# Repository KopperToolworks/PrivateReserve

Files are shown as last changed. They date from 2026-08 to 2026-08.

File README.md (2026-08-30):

# Private Reserve

Private Reserve is a door controller for openings that a stock garage opener is a poor fit for: a concealed or architectural door, a 140 V DC motor without the manufacturer's logic board, and a close that must seat against the frame rather than hit a hard stop.

It follows a Door-pace S-curve on remaining throw (peak g and cruise speed) instead of switching the motor full-on. A magnetic shaft encoder is the position source. Near-end markers only flag the last fraction of travel. Motor current both stops an obstruction mid-stroke and, after the close marker, snugs the door shut. The same firmware takes commands from a magnetic trigger, dual rocker stations, the on-box knob and LCD, and a phone web page that shares that LCD state.

The trigger is a hall sensor. A magnet placed over it opens the door. The magnet can be hidden in an object; the recess in the bottom of a bottle is one example.

This repository holds operator documentation, as-built wiring notes, and the production firmware image.

The on-box LCD during an open, and the empty-rack current table that sets the mid-stroke trip. The phone web page shows the same state.

<table>
<tr>
<th width="50%" align="center" valign="top">Main, opening</th>
<th width="50%" align="center" valign="top">Diagnostics, current table</th>
</tr>
<tr>
<td width="50%" align="center">
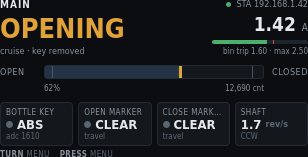
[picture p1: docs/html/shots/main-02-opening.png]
Main screen while the door is opening

</td>
<td width="50%" align="center">
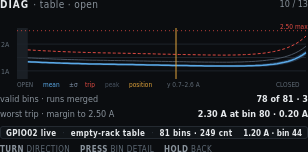
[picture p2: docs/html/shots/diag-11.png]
Diagnostics current table from open to closed

</td>
</tr>
<tr>
<td width="50%" align="center" valign="top">Travel, motor current, bottle key, and shaft while the door is moving.</td>
<td width="50%" align="center" valign="top">Empty-rack current from open to closed: mean, ±σ, and trip. The yellow mark is live position.</td>
</tr>
</table>

## Control network

| Item | Value |
| --- | --- |
| Fallback AP name (SSID) | `PrivateReserve` |
| Fallback AP password | `reserved` (WPA2) |
| SoftAP HTTP | `http://192.168.4.1/` |
| Set site Wi-Fi | `http://192.168.4.1/wifi` |
| mDNS (after STA join) | `http://private-reserve.local/` |
| OTA hostname | `private-reserve` |

Join the AP, type the password, then open the HTTP address. The LCD shows the join password on Settings → Network. Station (house) SSID and password do not belong in this repository.

## Layout

| Path | Contents |
|---|---|
| [`docs/`](docs/) | Operator docs. Software and wiring HTML in [`docs/html/`](docs/html/), PDF guides in [`docs/pdf/`](docs/pdf/). Rebuild with [`docs/build.mjs`](docs/build.mjs). |
| [`firmware/`](firmware/) | Production operator image (`tdisplay_s3_prod`). Source, PlatformIO env, and the shipped [`.bin`](firmware/images/tdisplay_s3_prod.bin). |
| [`schematics/`](schematics/) | Service drawings. Board A: [`schematics/Board_A.svg`](schematics/Board_A.svg) (`gen_board_a.py`). Board B: [`schematics/Board_B.svg`](schematics/Board_B.svg) (`gen_board_b.py`). Board C: [`schematics/Board_C.svg`](schematics/Board_C.svg) (`gen_board_c.py`). Manufacturer datasheets for Boards A, B, and C are in [`schematics/datasheets/`](schematics/datasheets/). |
| [`models/`](models/) | Printable `.3mf` bodies. Sensor puck, rotary-encoder cover, Board A Perma-Proto standoff, ACS712 mount. See [`models/README.md`](models/README.md). |

## Operator docs

Index: [`docs/README.md`](docs/README.md).

| Guide | HTML | PDF |
|---|---|-----|
| Software User Manual | [`docs/html/software-manual.html`](docs/html/software-manual.html) | [`docs/pdf/Software_User_Manual.pdf`](docs/pdf/Software_User_Manual.pdf) |
| Wiring Guide | [`docs/html/wiring-guide.html`](docs/html/wiring-guide.html) | [`docs/pdf/Wiring_Guide.pdf`](docs/pdf/Wiring_Guide.pdf) |

Software chapters: [Overview](docs/html/index.html), [Main](docs/html/main.html), [Calibration](docs/html/calibration.html), [Diagnostics](docs/html/diagnostics.html), [Settings](docs/html/settings.html).

Wiring chapters: [Board A](docs/html/board-a/index.html), [Board B](docs/html/board-b/index.html), [Board C](docs/html/board-c/index.html).

Rebuild from [`docs/`](docs/):

```bash
cd docs
npm install
./node_modules/.bin/playwright install chromium
npm run build
```

HTML in [`docs/html/`](docs/html/) is the source. The build reprints the chapter PDFs and the two bound guides.

## Firmware

See [`firmware/README.md`](firmware/README.md). The last published binary is [`firmware/images/tdisplay_s3_prod.bin`](firmware/images/tdisplay_s3_prod.bin).

## Secrets

Station (house) Wi-Fi credentials do not belong in this repository. Fallback SoftAP name and password are public and live in [`firmware/src/wifi_secrets.h`](firmware/src/wifi_secrets.h): `PrivateReserve` / `reserved`. They are also on the LCD and in the operator docs. ArduinoOTA auth is `reserve-ota` in that same file.

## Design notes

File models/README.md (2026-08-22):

# Printable models

Latest `.3mf` bodies for the parts that ship with the controller. Print these; shop FreeCAD sources stay in the design tree.

| File | Part |
|---|---|
| [`Sensor Puck - v03.3mf`](Sensor%20Puck%20-%20v03.3mf) | Hall-sensor bottle-key puck |
| [`Rotary Encoder Cover10-Body.3mf`](Rotary%20Encoder%20Cover10-Body.3mf) | AS5600 shaft-encoder cover |
| [`Dual PermaProto Standoff-Body.3mf`](Dual%20PermaProto%20Standoff-Body.3mf) | Board A dual Perma-Proto standoff |
| [`Current Load Sensor Mount - v3.3mf`](Current%20Load%20Sensor%20Mount%20-%20v3.3mf) | ACS712 DIN current-sensor mount |

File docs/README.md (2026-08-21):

# Operator docs

HTML lives in [`html/`](html/). PDF guides live in [`pdf/`](pdf/). Edit the
HTML under [`html/`](html/), then rebuild.

## Guides

The software manual and the wiring guide are sibling PDFs in `pdf/`. They
are not chapters of each other.

| Guide | File |
|---|---|
| Software User Manual | [pdf/Software_User_Manual.pdf](pdf/Software_User_Manual.pdf) |
| Software User Manual (HTML) | [html/software-manual.html](html/software-manual.html) |
| Wiring Guide | [pdf/Wiring_Guide.pdf](pdf/Wiring_Guide.pdf) |
| Wiring Guide (HTML) | [html/wiring-guide.html](html/wiring-guide.html) |

## Software chapters (HTML)

| Page | Chapter PDF |
|---|---|
| [Overview](html/index.html) | [pdf/software/index.pdf](pdf/software/index.pdf) |
| [Main](html/main.html) | [pdf/software/main.pdf](pdf/software/main.pdf) |
| [Calibration](html/calibration.html) | [pdf/software/calibration.pdf](pdf/software/calibration.pdf) |
| [Diagnostics](html/diagnostics.html) | [pdf/software/diagnostics.pdf](pdf/software/diagnostics.pdf) |
| [Settings](html/settings.html) | [pdf/software/settings.pdf](pdf/software/settings.pdf) |

## Wiring chapters (HTML)

| Page | Chapter PDF |
|---|---|
| [Board A](html/board-a/index.html) | [pdf/wiring/board-a.pdf](pdf/wiring/board-a.pdf) |
| [Board B](html/board-b/index.html) | [pdf/wiring/board-b.pdf](pdf/wiring/board-b.pdf) |
| [Board C](html/board-c/index.html) | [pdf/wiring/board-c.pdf](pdf/wiring/board-c.pdf) |

## Rebuild

From this directory:

```bash
npm install
./node_modules/.bin/playwright install chromium
npm run build
```

`html/` is the source. The script rebuilds the combined HTML pages and the
PDFs (`pdf/Software_User_Manual.pdf` and `pdf/Wiring_Guide.pdf`).

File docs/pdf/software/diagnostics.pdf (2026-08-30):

Private Reserve · DIN controller · first draft

# Diagnostics

One screen per input or output. Focused content is large. Every detail page names the GPIO and Board A terminal and shows the live level. Supporting values stay small. Header prefix is DIAG ·.

Draft. Pixel layout: UI/diagnostics.html. Terminal numbers match Board A.

Both jog pages, run to limit, and the obstruction test own the motor. They carry an amber banner while live. Hall and rocker cannot preempt them. HOLD cancels: PWM off, current decay, K1 unchanged. A short PRESS while moving also drops PWM (sampled in the main loop, not an interrupt). Jog by time queues milliseconds per EC11 detent. While that move is running it does not read the shaft encoder, so a NACK on I²C cannot stretch the queue. Leftover queue time expires on its own. Jog by position queues relative shaft counts. It does not need a known origin. It runs only while the AS5600 ACKs and the magnet is in range; a lost encoder stops PWM. Opening that page polls the encoder. Run to limit starts a jog-duty open or close and stops on the destination marker or PRESS. The shaft encoder is not read while that run is moving. Markers do stop this page. The learned envelope does not.

Private Reserve · Software User Manual · Diagnostics | 1 / 27

### 1. Menu

Fourteen items. TURN windows the list. Pips flag anything already unhealthy. PRESS opens. HOLD exits to Main. Figure 1 is an older 12-item shot; live firmware splits jog into time and position and adds run to limit. Items after the first window have their own figures below.

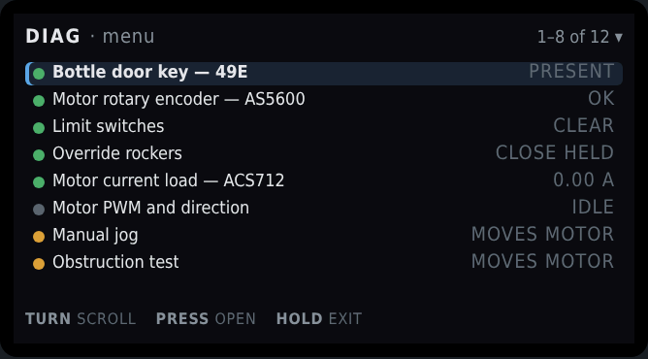
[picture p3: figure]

Figure 1. DIAG · menu. First window, bottle key selected. Live list also has Jog by time and Jog by position.

Private Reserve · Software User Manual · Diagnostics | 2 / 27

On screen | Meaning
DIAG · menu | Header left.
1–6 of 14 ▾ (live) or the older 1–8 of 12 shot | Header right. Window into the 14-item list. The triangle means more items below.
Green pip + highlight + Bottle door key — 49E + PRESENT | Selected. Hall sensor. Value is live cooked state.
Green pip + Motor rotary encoder — AS5600 + OK | I²C ACK and shaft magnet in range. Amber pip + no mag means the bus is live but STATUS is lost, too weak, or too strong. Red pip + no i2c means the chip did not ACK at 0x36.
Green pip + Limit switches + CLEAR | Neither marker is made.
Green pip + Override rockers + CLOSE HELD | Close throw is made right now. Centre does nothing. PRESS on that page pulses a throw through the same path as the hardware.
Green pip + Motor current load — ACS712 + 0.00 A | Live amps at rest.
Grey pip + Motor PWM and direction + IDLE | Duty zero. Grey pip is idle, not a fault.
Amber pip + Jog by time + no encoder | Amber because this page can command the motor. Timed detents. Shaft encoder is not read.
Amber pip + Jog by position + needs enc or red locked | Count detents. Green magnet required. Locked if I²C or magnet is unhealthy.
Amber pip + Run to limit + no encoder | Amber because this page can command the motor. Full travel at jog duty until the destination marker or PRESS.
Amber pip + Obstruction test + MOVES MOTOR | Same warning. Plastic-bottle test. Does not write the learned table.
TURN scroll · PRESS open · HOLD exit | Window the list, enter the highlighted item, or return to Main.

Full list:

Private Reserve · Software User Manual · Diagnostics | 3 / 27

# | Menu item | Value column | Opens

7 | Jog by time | no encoder | Milliseconds per detent. Encoder unused.
8 | Jog by position | needs enc / locked | Counts per detent. Requires a healthy AS5600.
9 | Run to limit | no encoder | Open or close until the destination marker. Encoder unused.
10 | Obstruction test | moves motor | Plastic-bottle envelope test.
11 | Obstruction table | armed / stale | Close-direction graph first. TURN swaps to open.
12 | EC11 knob and button | ok | Quadrature, detent scale, display timeout remaining.
13 | Network and OTA | STA or AP | Address, mDNS, antenna note.
14 | Stored calibration | ok / setup | Which steps are valid and why a stale one failed.

Every detail page keeps a pin strip: GPIO, terminal, function, live level or raw value. HOLD back returns to this menu. Bottle key, limit markers, and override rockers can inject a cooked signal from PRESS. The pin strip stays the real GPIO.

Private Reserve · Software User Manual · Diagnostics | 4 / 27

### 2. Bottle door key — 49E

Present and absent are two calibrated levels with separate enter and exit thresholds. Polarity is stated in words because it is configurable. PRESS can pulse the cooked state without moving the bottle.

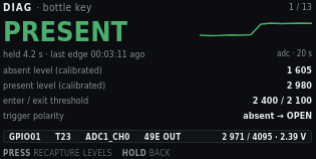
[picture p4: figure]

Figure 2. DIAG · bottle key. Present, last edge 3 min 11 s ago.

Private Reserve · Software User Manual · Diagnostics | 5 / 27

On screen | Meaning
DIAG · bottle key | Header left.
1 / 15 | Header right. First of fifteen detail screens. The menu is not numbered here.
PRESENT (green) | Hero. Cooked state after hysteresis. Amber plus SIM when PRESS has forced the state.
pulse · adc 2971 · last edge … | Selected action (pulse or recapture), live ADC, and age of the last cooked edge. Sparkline is the real ADC, newest at the right.
Sparkline + adc · 8 s | Raw ADC, newest at the right (dot). About 8 seconds once the strip is full. The trace scrolls left. The step up is the bottle going in.
absent level (calibrated) · 1 605 | Stage 9 absent capture.
present level (calibrated) · 2 980 | Stage 9 present capture.
enter / exit threshold · 2 400 / 2 100 | Hysteresis pair derived from those levels.
trigger polarity · absent → OPEN | Automatic Main command when the key leaves the recess.
Pin strip: GPIO01 · T23 · ADC1_CH0 · 49E OUT | MCU pin, Board A terminal, ADC channel, sensor output name. Always the real pin, even during a pulse.
2 971 / 4095 · 2.39 V | Live raw and volts at the pin.
TURN action | Pulse the key, or recapture levels. Pulse is the default. The highlight stops at each end. Extra clicks do not wrap.
PRESS pulse | Toggle cooked present/absent. Fires the same open/close edge as the hall sensor. Does not fake the ADC.
PRESS recapture | After TURN: capture absent, then PRESS again with the bottle in. Same two-step as Calibration stage 9.
HOLD back | Return to the diagnostic menu. Clears a simulated key state.
Private Reserve · Software User Manual · Diagnostics | 6 / 27

### 3. Motor rotary encoder — AS5600

The only source of door position. It also carries the jitter band and the drift from the last marker re-sync. I²C health and magnet STATUS are separate: ACK with no mag on the menu means the chip answered and the magnet is unreadable.

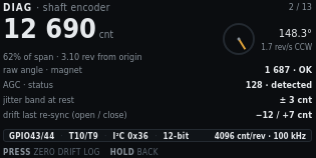
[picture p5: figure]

Figure 3. DIAG · shaft encoder. 62% of span, magnet OK.

Private Reserve · Software User Manual · Diagnostics | 7 / 27

On screen | Meaning
DIAG · shaft encoder | Header left.
2 / 15 | Header right.
12 690 cnt | Hero. Accumulated counts from the open origin.
62% of span · 3.10 rev from origin | Share of measured span, and shaft revolutions since origin.
Angle dial | Single-turn AS5600 angle inside the current revolution. Not the multi-turn door position.
148.3° | That single-turn angle in degrees.
1.7 rev/s CCW | Live shaft speed and direction.
I2C 0x36 · ACK or NACK | Live bus. ACK means the last STATUS/angle read succeeded. Magnet can still be unreadable.
raw angle · magnet · 1 687 · detected | 12-bit raw angle (0–4095) and STATUS: detected, lost, too weak, too strong, or unread if the bus failed.
AGC (mid ~128) · 128 | Automatic gain. Meaningful only on ACK. Mid-range is a healthy air gap.
jitter band at rest · ± 3 cnt | Stage 1b capture. Growing band is an early warning for a weak magnet.
drift last re-sync (open / close) · −12 / +7 cnt | Correction applied the last time each marker was seen. Growing drift means lost turns or a slipping magnet.
Pin strip: GPIO43/44 · T10/T9 · I²C 0x36 · 12-bit | SCL/SDA, terminals, bus address, resolution.
4096 cnt/rev · 100 kHz | Counts per mechanical revolution and I²C clock.
PRESS zero drift log | Clear the displayed per-marker drift totals. Does not change origin.
HOLD back | Return to the menu.
Private Reserve · Software User Manual · Diagnostics | 8 / 27

### 4. Limit switches

HIGH is the marker state. A cut wire is indistinguishable from a made switch, so the screen says so. Both markers active is a fault, shown here rather than as a silent refusal to start. PRESS can force a marker without blocking the optical path.

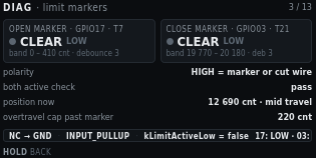
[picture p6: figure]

Figure 4. DIAG · limit markers. Both clear, mid travel.

Private Reserve · Software User Manual · Diagnostics | 9 / 27

On screen | Meaning
DIAG · limit markers | Header left.
3 / 15 | Header right.
Open marker · GPIO17 · T7 | Left tile title. Pin and Board A terminal.
Grey pip + CLEAR LOW | Open switch not made. Electrical level is LOW.
band 0 – 410 cnt · debounce 3 | Count window where an open-marker actuation is accepted, and debounce samples.
Close marker · GPIO03 · T21 | Right tile title.
Grey pip + CLEAR LOW | Close switch not made.
band 19 770 – 20 180 · deb 3 | Close-marker acceptance window and debounce.
polarity · HIGH = marker or cut wire | NC to GND with pull-up. HIGH means the loop is open: at the end, or the wire is cut.
both active check · pass | Both markers made at once is a fault. Pass means that is not happening.
position now · 12 690 cnt · mid travel | Live counts and a cooked region name.
overtravel cap past marker · 220 cnt | Hard cap after a marker. A seek that passes this is a fault.
Pin strip: NC → GND · INPUT_PULLUP · kLimitActiveLow = false | Wiring and the firmware polarity constant.
17: LOW · 03: LOW | Live GPIO17 and GPIO3 levels. Stays the real pin during a force.
TURN select · PRESS force | Highlight open or close. The highlight stops at each end. Extra clicks do not wrap. PRESS latches that marker as if the switch were made. Amber pip and SIM on the tile. PRESS again clears that force. A forced destination marker will stop a move already in progress.
HOLD back | Return to the menu. Clears a forced marker.
Private Reserve · Software User Manual · Diagnostics | 10 / 27

### 5. Override rockers

Two paralleled stations act as one logical switch. Each throw is shown separately. A stuck throw is invisible if you only display the combined result. Both throws at once is a defined tie-break, not a fault. PRESS pulses the selected throw through the same path as the hardware.

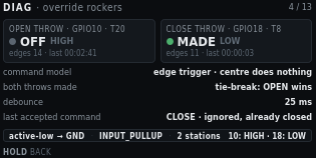
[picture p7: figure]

Figure 5. DIAG · override rockers. Close throw held.

Private Reserve · Software User Manual · Diagnostics | 11 / 27

On screen | Meaning
DIAG · override rockers | Header left.
4 / 15 | Header right.
Open throw · GPIO10 · T20 | Left tile. Open side of both paralleled stations.
Grey pip + OFF HIGH | Open throw not made. Pulled up.
edges 14 · last 00:02:41 | Accepted edges since boot, and age of the last open edge.
Close throw · GPIO18 · T8 | Right tile.
Green pip + MADE LOW | Close throw is held to ground right now.
edges 11 · last 00:00:03 | Close-edge count and the edge three seconds ago.
command model · edge trigger · centre does nothing | Rocker centre is idle. Hold-to-run is not the model.
both throws made · tie-break: OPEN wins | If both throws hit in the same cycle, firmware commands open.
debounce · 25 ms | Switch debounce. Same family as Settings → Triggers.
last accepted command · CLOSE · ignored, already closed | Last edge that passed debounce, and why it did not start a move.
Pin strip: active-low → GND · INPUT_PULLUP · 2 stations | Wiring. Two stations in parallel hide a stuck mate unless this page splits the throws.
10: HIGH · 18: LOW | Live GPIO10 and GPIO18. Stays the real pin during a pulse.
TURN select · PRESS pulse | Highlight open or close. The highlight stops at each end. Extra clicks do not wrap. PRESS injects a short made-edge on that throw, the same command as the physical rocker. It can start a move. Amber pip and SIM while the pulse is live.
HOLD back | Return to the menu. Drops a pulse that has not expired.
Private Reserve · Software User Manual · Diagnostics | 12 / 27

### 6. Motor current load — ACS712-05B

Live amps against the learned envelope for the bin the door is in. Trip is a time-plus-threshold decision, so inrush skip and hold time are on the same page.

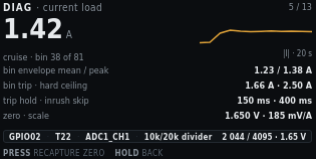
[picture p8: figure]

Figure 6. DIAG · current load. Live 1.42 A in cruise.

On screen | Meaning
DIAG · current load | Header left.
5 / 15 | Header right.
1.42 A | Hero. Cooked motor current.
cruise · bin 38 of 81 | Motion phase and which obstruction bin the door is in.
Sparkline + |I| · 8 s | Absolute current, newest at the right (dot). About 8 seconds once the strip is full. The trace scrolls left. The step up is the start of cruise.
bin envelope mean / peak · 1.23 / 1.38 A | Learned mean and peak for bin 38.
bin trip · hard ceiling · 1.66 A · 2.50 A | This bin’s trip, then the compile-time ceiling.
trip hold · inrush skip · 150 ms · 400 ms | How long current must stay over trip, and how long after PWM-on the envelope is ignored.
zero · scale · 1.650 V · 185 mV/A | Stage 1a zero and the fixed ACS712-05B scale.
Pin strip: GPIO02 · T22 · ADC1_CH1 · 10k/20k divider | Pin, terminal, ADC channel, Board A divider.
2 044 / 4095 · 1.65 V | Live raw and volts. Near the rest zero, plus load.
PRESS recapture zero | Jump to Calibration stage 1a. Motor must be at rest.
HOLD back | Return to the menu.
Private Reserve · Software User Manual · Diagnostics | 13 / 27

### 7. Motor PWM and direction

Duty and K1 are separate blocks. Duty must reach zero and current must decay before the relay moves, so the blank timers are on this page.

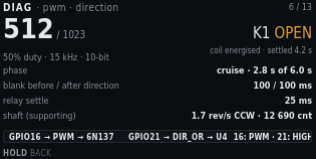
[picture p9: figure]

Figure 7. DIAG · pwm · direction. 50% duty, K1 open.

On screen | Meaning
DIAG · pwm · direction | Header left.
6 / 15 | Header right.
512 / 1023 | Hero. Live duty in 10-bit counts.
50% duty · 15 kHz · 10-bit | Percent, carrier, resolution. Carrier is compile-time. It is not a setting.
K1 OPEN (amber) | Direction relay commanded open. Amber because the coil is energised.
coil energised · settled 4.2 s | K1 has been in this state long enough to be settled.
phase · cruise · N cnt left | Profile phase and remaining counts to the destination marker. Not a cruise-time timer.
blank before / after direction · 100 / 100 ms | PWM-off windows around a K1 change. Never reverse K1 without this blanking.
relay settle · 25 ms | Wait after K1 before PWM may rise.
shaft (supporting) · 1.7 rev/s CCW · 12 690 cnt | Encoder as a supporting signal on this page. The focused page is PWM.
Pin strip: GPIO16 → PWM → 6N137 · GPIO21 → DIR → U4 | PWM path onto Board B, and direction into U4.
16: PWM · 21: HIGH | GPIO16 is toggling. GPIO21 is HIGH for open on this build.
HOLD back | Return to the menu. This page does not command the motor.
Private Reserve · Software User Manual · Diagnostics | 14 / 27

### 8. Jog by time

Owns the motor. Each EC11 detent (or web − / +) queues a fixed run time at jog duty. Same-direction clicks add to that queue. Opposite clicks subtract; when the queue is gone, that click reverses through the normal PWM-off, decay, blank, and K1 settle windows. PRESS while idle cycles duty (5–25%) and time per detent (200–1000 ms). While that timed move is running, the shaft encoder is not polled, so I²C NACKs cannot stretch the queue. Idle on this page still reads the AS5600 (same as most diagnostic screens). After PWM stops, one catch-up read refreshes STATUS. Markers and the learned envelope do not start, stop, or abort the move. Current is a live 0–2.50 A graph when the ACS712 is sampling; it is display-only. The pin strip reads encoder ignored.

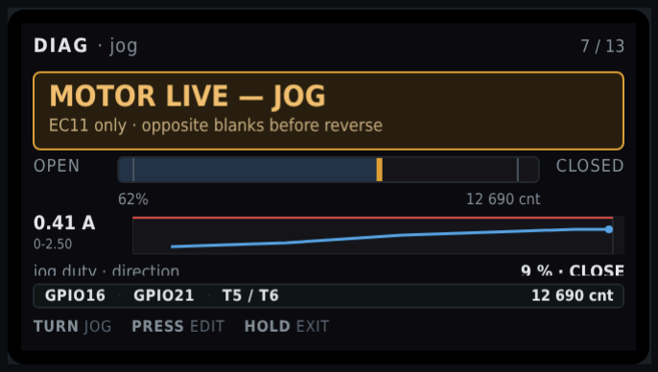
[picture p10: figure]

Figure 8. DIAG · jog by time. Timed queue. Live firmware titles the page MOTOR LIVE — TIME and omits the travel widget.

Private Reserve · Software User Manual · Diagnostics | 15 / 27

On screen | Meaning
DIAG · jog by time | Header left.
7 / 15 | Header right.
MOTOR LIVE — TIME | Amber banner. This page owns the motor. Hall and rocker cannot preempt it.
encoder unused — time per detent | Banner detail. AS5600 I²C is skipped only while the timed queue is moving, not while this page is idle.
jog duty · direction · 9 % · CLOSE | Jog PWM as a percent of 10-bit full scale (5–25%). K1 for this jog. PRESS while idle highlights this row; TURN changes it.
step · remaining · 400 ms · 800 ms | Time added per detent (200–1000 ms, 50 ms steps) and how much powered time is still queued. Queue caps at 4 s. Remaining is wall-clock, not loop ticks.
Live amp strip · 0–2.50 scale | ACS712 history. Display-only. Not used to run or stop the jog.
Pin strip: GPIO16 · GPIO21 · encoder ignored | PWM and direction only. No shaft counts on this page.
TURN jog or TURN duty / TURN step | Default: CW queues close, CCW queues open. Same way extends. Opposite shortens, then blanks and reverses.
PRESS stop or PRESS edit / PRESS next | While moving: drop PWM on a short click (after debounce, on release). While idle: cycle Jog → duty % → step ms → Jog.
HOLD exit | Stop if moving, save a pending edit, then return to the menu.
Private Reserve · Software User Manual · Diagnostics | 16 / 27

### 9. Jog by position

Owns the motor only while the AS5600 ACKs and STATUS shows a magnet that is neither too weak nor too strong. That is not a trusted origin; calibration is not required. The queue is relative: each detent is shaft counts in the commanded direction from the live unwrap, not distance from open or close. The pin strip may still show accumulated counts from origin when origin is trusted. Opening this page cancels a leftover time-jog move and forces an encoder poll so the lock banner is not a stale STATUS from a skipped I²C window. Each detent uses the same jog duty (default 64 counts, 16–512 in steps of 16). Same-direction clicks extend the count queue (cap 2048). Opposite clicks subtract, then reverse through the same blanking path as time jog. The stall watchdog is armed when PWM starts so an old timer cannot trip on the first frame. Travel-cap (absolute) is not applied on this page. If I²C fails or STATUS drops out of range, PWM stops immediately without latching a sensor fault. While locked, the banner title is ENCODER REQUIRED and the subtitle names the check that failed. No dedicated LCD shot in this set; chrome matches time jog with counts in place of milliseconds.

Private Reserve · Software User Manual · Diagnostics | 17 / 27

On screen | Meaning
DIAG · jog by position | Header left.
8 / 15 | Header right.
MOTOR LIVE — COUNTS | Amber banner when I²C ACK and STATUS are good. TURN jogs.
stops if encoder is lost | Banner detail when the sensor is good.
ENCODER REQUIRED | Amber banner. Jog is locked. TURN does not move the motor.
I2C NACK - chip unread at 0x36 | Banner detail. The AS5600 did not ACK. Not a magnet STATUS flag. Bus time is the 10 ms Wire timeout on a failed transfer; too-weak/too-strong do not change that time.
STATUS: magnet too weak | Banner detail. Chip ACKed. STATUS bit “too weak.” Angle was read and discarded.
STATUS: magnet too strong | Banner detail. Chip ACKed. STATUS bit “too strong.”
STATUS: magnet lost | Banner detail. Chip ACKed. Magnet-detect bit clear (and not the too-weak/too-strong pair).
Travel widget | Shown. Live counts and magnet label on the pin strip (AS5600 T5 / T6).
jog duty · direction | Same 5–25% duty as time jog. Shared setting.
step · remaining · counts | Relative counts per detent and remaining in the commanded direction. Not a target absolute position.
TURN jog | Ignored while locked. Otherwise same CW close / CCW open as time jog.
PRESS stop / HOLD exit | Same cancel rules as time jog.
Private Reserve · Software User Manual · Diagnostics | 18 / 27

### 10. Run to limit

Owns the motor. TURN selects open (GPIO17 / upper marker) or close (GPIO03 / lower marker). PRESS while idle starts a run at jog duty through the same PWM-off, decay, blank, and K1 settle windows as every other direction change. PRESS while moving drops PWM. HOLD cancels and returns to the menu. The run stops itself when the destination marker is made after debounce. It does not creep, snug, or re-sync origin. Calibration is not required. The shaft encoder is not polled while the run is moving, so an I²C NACK cannot abort it. Idle on this page still reads the AS5600. After PWM stops, one catch-up read refreshes STATUS. Start is refused if that destination marker is already made. Both markers still latch LimitHit. Hard overcurrent and the move timeout still apply. Stall, travel-cap, and the learned envelope do not. Current is a live 0–2.50 A graph when the ACS712 is sampling; it is display-only except for the hard ceiling. The pin strip reads encoder ignored. Duty is the shared jog-duty setting (5–25%), not cruise.

On screen | Meaning
DIAG · run to limit | Header left.
9 / 15 | Header right.
MOTOR LIVE — LIMIT | Amber banner. This page owns the motor. Hall and rocker cannot preempt it.
encoder unused — stop on marker | Banner detail. AS5600 I²C is skipped only while the run is moving. A refused start (already at that marker) replaces this line with the hint.
Open / close tiles | TURN highlights the end to run toward. Live marker state: CLEAR or AT MARK.
jog duty · phase | Shared 5–25% jog PWM and the live blanking or run-to-limit phase.
Live amp strip · 0–2.50 scale | ACS712 history. Display-only except hard overcurrent.
Pin strip: GPIO16 · GPIO21 · encoder ignored | PWM and direction only.
TURN select | Idle only. Ignored while moving so a detent does not abort.
PRESS run / PRESS stop | Idle: start toward the highlighted end. Moving: drop PWM.
HOLD exit | Stop if moving, then return to the menu.
Private Reserve · Software User Manual · Diagnostics | 19 / 27

### 11. Obstruction test

Plastic bottle between the doors. Same envelope rules as Main. Does not write the learned table. Learn runs assume a clear path. This test is not a substitute for them.

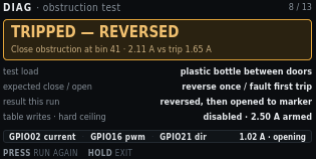
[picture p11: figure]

Figure 9. DIAG · obstruction test. Close trip, reversed, opening.

On screen | Meaning
DIAG · obstruction test | Header left.
10 / 15 | Header right.
TRIPPED — REVERSED | Amber banner title. Close obstruction fired. Reverse is in progress or just finished.
Close obstruction at bin 41 · 2.11 A vs trip 1.65 A | Where and how far over trip.
test load · plastic bottle between doors | Specified test article. Not a body part, not a tool.
expected close / open · reverse once / fault first trip | Close reverses once. Open faults on the first trip. Same as Main.
result this run · reversed, then opened to marker | What this test actually did.
table writes · hard ceiling · disabled · 2.50 A armed | A deliberate obstruction cannot be taught as load. The ceiling stays on.
Pin strip: GPIO02 current · GPIO16 pwm · GPIO21 dir | Signals this test uses.
1.02 A · opening | Live current and direction after reverse.
PRESS run again | Start another close into the bottle.
HOLD exit | Cancel if live, then return to the menu.
Private Reserve · Software User Manual · Diagnostics | 20 / 27

### 12. Obstruction table — close direction

Learned envelope as a curve. Breakaway at the open end and seal loading at the close end are the shape you want. A bump in the middle is a bind. The grey block past the close marker is travel the learn runs never enter, because snug is a separate window.

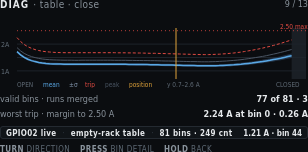
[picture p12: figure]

Figure 10. DIAG · table · close. Empty-rack table, live at bin 44.

Private Reserve · Software User Manual · Diagnostics | 21 / 27

On screen | Meaning
DIAG · table · close | Header left. Close-direction envelope.
11 / 15 | Header right. Menu item 11 is this pair of graphs.
1A / 2A on the Y axis | Current scale. The window is 0.7–2.6 A so the curve is readable on 170 pixels.
Dashed red line + 2.50 max | Compile-time hard ceiling. Not a learned value.
Blue mean curve | Merged mean current per bin from the learn runs.
Grey band ±σ | One-sigma band around the mean.
Dashed red trip curve | Per-bin trip used on Main.
Thin grey peak curve | Highest sample merged into that bin.
Vertical amber position line | Live door position on this graph.
Dark block near CLOSED | Bins past the close marker. Learn runs never visit them. Snug is a separate window.
Legend: OPEN · mean · ±σ · trip · peak · position · y 0.7–2.6 A · CLOSED | X ends and the plotted series. Y window is stated so the clipped axis is not mistaken for 0–2.50 A.
valid bins · runs merged · 77 of 81 · 3 | Bins with data, and how many strokes were merged.
worst trip · margin to 2.50 A · 2.24 A at bin 0 · 0.26 A | Highest trip on this table (breakaway at the open end) and room left to the ceiling.
Pin strip: GPIO02 live · empty-rack table · 81 bins · 249 cnt | Which table is drawn, bin count, and bin width in counts.
1.21 A · bin 44 | Live current and the bin under the position line.
TURN direction | Swap to the open-direction graph.
PRESS bin detail | Numeric values for the bin under the cursor (not a separate mockup in this set).
HOLD back | Return to the menu.
Private Reserve · Software User Manual · Diagnostics | 22 / 27

### 13. Obstruction table — open direction

Same table, other direction. Breakaway is now at the closed end, where the door pulls out of the seal. The unvisited block moves to the open end. Two independent tables are why both views exist.

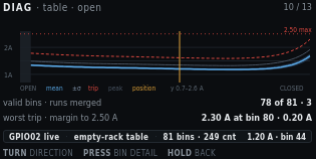
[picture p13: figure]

Figure 11. DIAG · table · open. Breakaway at the closed end.

On screen | Meaning
DIAG · table · open | Header left.
12 / 15 | Header right.
Graph, Y labels, 2.50 max, legend | Same series as the close graph. Shape differs: peak at the closed end.
Dark block near OPEN | Bins before the open marker. Open-direction learn runs never visit them.
valid bins · runs merged · 78 of 81 · 3 | Open-direction bins with data (bins at and after the open marker) and merged run count.
worst trip · margin to 2.50 A · 2.30 A at bin 80 · 0.20 A | Highest open-direction trip (breakaway at the closed end) and room left to the ceiling.
Pin strip: GPIO02 live · empty-rack table · 81 bins · 249 cnt | Same table family as the close view.
1.20 A · bin 44 | Live current and the bin under the position line, read against the open envelope.
TURN direction · PRESS bin detail · HOLD back | Same gestures as the close graph.
Private Reserve · Software User Manual · Diagnostics | 23 / 27

### 14. EC11 knob and button

An input with no other home. Detent scale is bench-calibrated, so raw quadrature and the scaled count sit side by side.

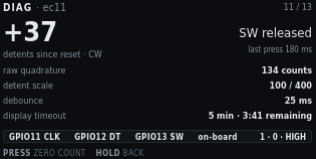
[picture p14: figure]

Figure 12. DIAG · ec11. Detent scale 100 / 400. Display timeout 5 min.

On screen | Meaning
DIAG · ec11 | Header left.
13 / 15 | Header right.
+37 | Hero. Scaled detents since reset. Sign is CW positive on this shot.
detents since reset · CW | What the hero counts, and last turn sense.
SW released | Knob switch is up.
last press 180 ms | Duration of the last PRESS (under the HOLD threshold).
raw quadrature · 134 counts | Unscaled CLK/DT edges. Compare with the detent hero to check the scale.
detent scale · 100 / 400 | Quadrature-to-detent fraction from ec11_calibration.h (kEc11DetentScaleNumerator / kEc11DetentScaleDenominator). 100/400 is one detent per four edges.
debounce · 25 ms | SW debounce.
display timeout · 5 min · 3:41 remaining | Idle blanking setting and time left until GPIO38 backlight and GPIO15 panel power drop. Default is 5 minutes.
Pin strip: GPIO11 CLK · GPIO12 DT · GPIO13 SW · on-board | EC11 on the T-Display-S3, not a Board A terminal.
1 · 0 · HIGH | Live CLK, DT, SW. SW HIGH is released with pull-up.
PRESS zero count | Reset the detent hero to 0. Does not change calibration constants.
HOLD back | Return to the menu.
Private Reserve · Software User Manual · Diagnostics | 24 / 27

### 15. Network and OTA

Setup surface. The steel lid can block the onboard antenna, so that note is on the screen, not only in the build docs. When SoftAP is serving, this page shows the join password in clear (default reserved). The AP name defaults to PrivateReserve. After join, open http://192.168.4.1/. PRESS rejoin retries the stored STA SSID. To drop that SSID, use Settings → Service → Clear station Wi-Fi, then reboot.

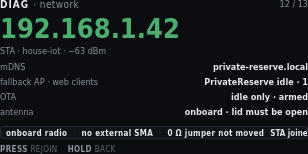
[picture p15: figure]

Figure 13. DIAG · network. STA joined, OTA idle-only.

On screen | Meaning
DIAG · network | Header left.
14 / 15 | Header right.
192.168.1.42 (green) | Hero. Station address when STA joined.
STA · house-iot · −63 dBm | Role, stored SSID, RSSI.
mDNS · private-reserve.local | mDNS name for HTTP on the joined LAN.
fallback AP · web clients · PrivateReserve idle · 1 | SoftAP name, idle because STA joined, and one HTTP client. If SoftAP is the live link, this row is join password and the WPA2 PSK (default reserved) instead.
OTA · idle only · armed | OTA is allowed only while the motor is idle. Armed means the endpoint is listening.
antenna · onboard · lid must be open | No external SMA. Close the steel lid and RSSI can collapse.
Pin strip: onboard radio · no external SMA · 0 Ω jumper not moved | Antenna path as shipped. Do not move the 0 Ω jumper unless you fit an external antenna.
STA joined | Live radio role.
PRESS rejoin | Retry STA join with the stored SSID. If join fails, SoftAP starts. This does not clear the stored password. To wipe station credentials, use Settings → Service → Clear station Wi-Fi, then reboot from that result screen or from Reboot controller.
HOLD back | Return to the menu.
Private Reserve · Software User Manual · Diagnostics | 25 / 27

### 16. Stored calibration

Answers whether this controller may run automatically, and why not. Stale entries name the value that invalidated them.

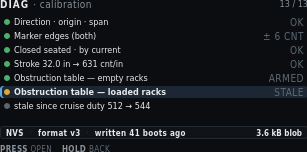
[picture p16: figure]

Figure 14. DIAG · calibration. Loaded table stale after cruise duty 512 → 544.

On screen | Meaning
DIAG · calibration | Header left.
15 / 15 | Header right. Last detail screen.
Green pip + Direction · origin · span + OK | Stages 2–4 stored and valid.
Green pip + Marker edges (both) + ± 6 CNT | Open/close probe spread still inside tolerance. The value column shows the open-side figure on this shot.
Green pip + Closed seated · by current + OK | Stage 5 method still current-rise.
Green pip + Stroke 32.0 in → 631 cnt/in + OK | Stage 6 still matches the stored span.
Green pip + Obstruction table — empty racks + ARMED | Empty envelope is in service.
Amber pip + highlight + Obstruction table — loaded racks + STALE | Selected. Loaded table is not usable.
Grey pip + stale since cruise duty 512 → 544 | Why. A motion-profile change invalidates both tables. This row names the field that did it.
Pin strip: NVS · format v3 · written 41 boots ago | Where the blob lives, format, age in boots (no RTC).
3.6 kB blob | Stored size.
PRESS open | Jump to the matching Calibration stage for the highlighted row.
HOLD back | Return to the menu.
Private Reserve · Software User Manual · Diagnostics | 26 / 27

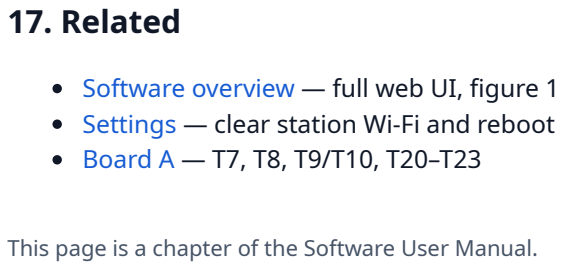
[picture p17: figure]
17. Related; Board A — T7, T8, T9/T10, T20–T23

Software overview — full web UI, figure 1 Settings — clear station Wi-Fi and reboot

This page is a chapter of the Software User Manual.

Private Reserve · Software User Manual · Diagnostics | 27 / 27

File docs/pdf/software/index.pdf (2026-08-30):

Private Reserve · DIN controller · first draft

## Software — operator UI

Production image tdisplay_s3_prod on the LilyGo T-Display-S3 (Board A). The LCD and the phone web page share one controller state. The EC11 knob, the web keypad, the rockers, and the bottle-door key all go through one command arbiter.

Draft. These pages describe the operator screens as built. Each option has a 320 × 170 panel shot. Every label on that shot is named in a field table on Main, Calibration, Diagnostics, and Settings. The web page adds tabs and a keypad; figure 1 is a full-chrome example. Pixel source: UI mockups. Motion, obstruction, and NVS names remain specified in Production_Software.md and T-Display-S3_Firmware_Config.md.

No application login. Anyone who can reach the controller on the joined LAN, or join its fallback SoftAP, can monitor, configure, and command the door. HTTP is port 80. Do not expose that network to the public internet.

### 1. Surfaces

View the LCD with USB-C on the left and the EC11 on the right. Firmware uses Arduino_GFX rotation 3. The logical panel is 320 wide by 170 tall. Origin (0, 0) is the operator-facing top-left.

The web page is the same state tree plus chrome the LCD does not have: tabs across the top, a keypad on the right that maps to the knob. Use it in landscape on a phone. The layout scales to fill the viewport without clipping. STA in the header means the ESP32 joined site Wi-Fi as a station. AP means the fallback SoftAP is serving.

Surface | Role
LCD (ST7789) | In-box operator panel. Off means GPIO38 backlight and GPIO15 panel power only. The MCU stays up.
Web (port 80) | Same screens. Tabs jump to Main, Calibration, Diagnostics, Settings, or Docs. Keypad on the right: turn − / +, press (Return), hold (back). Figure 1.
EC11 | TURN scroll or adjust. PRESS open or accept. HOLD back or cancel.
GPIO14 | On-board T-Display button. Same PRESS / HOLD window as the knob switch. Does not revert a recent turn.
Private Reserve · Software User Manual · Overview | 1 / 8

### 1.1 Full web page

On site Wi-Fi, open http://private-reserve.local or the STA address on port 80. On the fallback AP, join PrivateReserve with password reserved, then open http://192.168.4.1/. The LCD shows only the 320 × 170 panel. The web page adds tabs on top and a keypad on the right. This shot is Documentation. The panel inside the bezel is the same DOC screen as Main figure 8.

Figure 1. Full web UI in landscape. Tabs jump modes. The keypad maps to the EC11.

On screen | Meaning
Main · Calibration · Diagnostics · Settings · Docs | Top tabs. Jump to that page. They turn the LCD on if it was blank. Same destinations as the mode menu.
Docs in white | Active tab. Other tabs stay blue. The controller is on the Documentation page.
Bezel, 320 × 170 | The LCD panel. Same state tree as the physical display. Header here is DOC with STA 172.16.0.68.
QR · github.com/ · KopperToolworks/PrivateReserve | Public project page. The web copy adds a blue Open GitHub page link the LCD does not have.
Top pair, circular arrows | TURN − (CCW) and TURN + (CW). Same as the knob.
Tall Return arrow | PRESS. On Documentation this does nothing.
Wide left arrow | HOLD back. From Documentation this returns to the mode menu.

### 2. Knob map

HOLD fires once when the push has been down for ec11_hold_min_ms (default 400 ms). It does not wait for release. A shorter down is PRESS. Keeping the button down does not fire a second HOLD. ec11_hold_max_ms remains a setting; it does not delay the first HOLD.

Private Reserve · Software User Manual · Overview | 2 / 8

Pressing the knob can twist CLK/DT. If the highlight moved within ec11_press_revert_ms (100 ms) of an EC11 press, firmware restores the previous item, then handles PRESS. Rotation is ignored while SW is down.

On bottle key, limit markers, and override rockers, TURN selects one of two choices. The highlight stops at the end instead of wrapping. Extra clicks in that direction do nothing. One click moves once.

Gesture | Typical meaning | Web keypad
TURN − / + | Scroll a list or change a pending value | Top pair, circular arrows
PRESS | Open a screen, start a stage, or accept | Large Return arrow
HOLD | Back one screen, or cancel a live procedure | Wide left arrow

### 3. Command priority

Hard overcurrent and sensor or limit faults outrank all commands. Obstruction handling outranks ordinary commands. Among ordinary sources the order is EC11 → web → rocker → hall. At most one state-changing command runs per control cycle.

A live calibration or diagnostic-jog step owns the motor. Hall and rocker events may show on the screen. They cannot preempt that step. Main accepts hall and rocker triggers. Diagnostics has two jog pages. Jog by time is an EC11 (or web keypad) millisecond queue. PRESS while idle edits duty (5–25%) and time per detent (200–1000 ms). The encoder is not polled while that queue is moving. Jog by position queues relative shaft counts (no origin required) and runs only while the AS5600 and magnet are healthy. Opening that page polls the encoder. Current still draws as a live graph when the ACS712 is sampling.

There is no operator Stop on Main. Cancel exists only for a running calibration or diagnostic procedure. Cancel removes PWM, waits for current decay, leaves K1 unchanged, discards incomplete results, and returns to that mode’s menu.

Never write NVS while the motor runs. Config writes need an idle motor.

### 4. Boot, blanking, Wi-Fi

The screen is on at boot. Default idle timeout is 5 minutes (display_timeout_ms = 300000). Any EC11 turn or press, GPIO14, or web command resets the timer. Wake from a blanked panel returns to Main.

Calibration, diagnostics, faults, and any prompt that needs an answer inhibit blanking. A latched PositionUnknown on Main does not hold the panel on forever. That fault is the default boot state until origin is found.

STA join uses the stored SSID and password. If the SSID is empty or join fails, firmware starts a SoftAP.

Private Reserve · Software User Manual · Overview | 3 / 8

Fallback AP | Default
Name (SSID) | PrivateReserve
Join password | reserved (WPA2, eight characters)
Main page | http://192.168.4.1/
Set site Wi-Fi | http://192.168.4.1/wifi

Type the join password on the phone. Then open the main page. The LCD shows that password on Settings → Network, on Diagnostics → Network while SoftAP is up, and on the Wi-Fi-cleared result. Station (house) password stays masked. When STA joins, HTTP is on the STA address and http://private-reserve.local. The steel lid can block the onboard antenna. That note belongs on the network diagnostic screen.

Settings → Service can clear the stored station SSID and password. That write is immediate. The live STA session stays until reboot. After reboot, empty SSID skips STA and starts SoftAP. Fallback AP name and password stay. The same Service list can reboot the controller (PRESS twice). PRESS on the Wi-Ficleared result screen also reboots. See Settings figures 11 and 12.

No automatic resume after reset. A watchdog, brownout, operator reboot, or power cycle forces PWM off and cancels the prior command.

### 5. Modes

Default after boot is Main (Standard Operating Mode in the spec). Settings and Documentation are not extra operating modes. They are menu pages reached the same way as Calibration and Diagnostics. Motion is idle while settings are edited.

Private Reserve · Software User Manual · Overview | 4 / 8

Page | Header | Panel shots | What it is
Main | MAIN or NEEDS SETUP | 8 Live door. Mode menu: Main, Diagnostics, Calibration, Settings, | Documentation.
Calibration | CAL · … | 13 | Guided stages. Path-clear before any move. Save is one NVS write on Review.
Diagnostics | DIAG · … | 14 | One screen per input or output. Two jog pages own the motor: time (encoder unused) and position (healthy AS5600 required). PRESS edits duty % and step. Current is a live graph. Obstruction test owns the motor. Bottle key, limit markers, and override rockers can inject a cooked signal from PRESS.
Settings | SET · … | 12 | Staged edits. Review commits. Service actions are destructive and confirm twice, including reboot and clear station Wi-Fi.
Documentation | DOC | 1 | QR and URL for the public GitHub page. HOLD returns to the mode menu. PRESS does nothing.
Private Reserve · Software User Manual · Overview | 5 / 8

Entry screens for each mode:

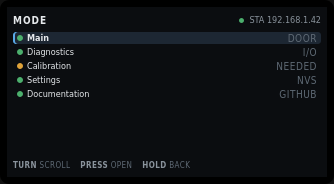
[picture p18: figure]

Figure 2. Mode menu on Main. PRESS opens the highlighted item.

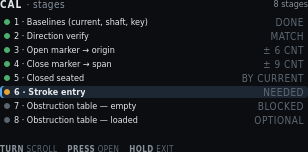
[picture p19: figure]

Figure 3. Calibration stage list. See Calibration for every stage.


Figure 4. Diagnostics menu. See Diagnostics for all twelve items.

Private Reserve · Software User Manual · Overview | 6 / 8

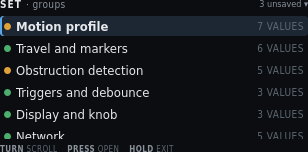
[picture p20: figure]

Figure 5. Settings groups. See Settings for edit, review, service, Wi-Fi clear, and reboot.

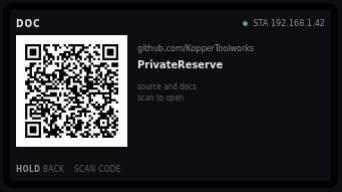
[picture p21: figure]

Figure 6. Documentation panel only. See Main · Documentation for every label on this panel. The full web chrome is figure 1.
Every label on these shots is named in the field table on the linked page.

### 6. Field I/O the screens name

Position is AS5600 counts from the open origin. Inches appear after stroke entry (open marker to close marker). Automatic moves use Door pace on remaining distance. The belt spring take-up is calibrated so a duty step is not treated as leaf motion. The three analog sensors stay independent.

Private Reserve · Software User Manual · Overview | 7 / 8

Name | Part | GPIO / Board A | Job
Bottle door key | 49E / SS49E | GPIO1, T23 | Magnet present or absent. Automatic open/close.
Shaft encoder | AS5600 | GPIO43/44, T10/T9 | Door position as accumulated counts. Diagnostics shows I²C ACK/NACK separately from magnet STATUS.
Current load | ACS712-05B | GPIO2, T22 | Motor current. Envelope and snug.
Open marker | NC switch | GPIO17, T7 | Near-end flag, open side.
Close marker | NC switch | GPIO3, T21 | Near-end flag, close side.
Override rockers | two paralleled stations | GPIO10 T20, GPIO18 T8 | Edge-trigger open/close. Centre does nothing.
Knob | EC11 | GPIO11–13, on-board | Menu, settings, cancel, acknowledge.

### 7. Needs setup

If origin, marker spans, or the calibration format is invalid, Main blocks automatic motion. Only guided calibration and diagnostic jog may move the motor. Time jog still runs without a trusted shaft position. Position jog needs a healthy encoder but not a known origin (relative counts). Duty and step are edited on those pages. Hall and rocker triggers stay disabled.

The AS5600 is single-turn. The stroke spans several turns. After power loss the firmware enters PositionUnknown and needs a guided seek to the open marker. Direction verify must pass before any limit seek.

With an invalid obstruction table, automatic Main motion stays blocked. Recovery uses the 2.50 A hard ceiling until a relearn arms the table.

### 8. Related

Board A — earth-side terminals the screens name Board B — floating gate driver
Board C — HV switch stage
Documentation — GitHub QR on the DOC page

This page is a chapter of the Software User Manual.

Private Reserve · Software User Manual · Overview | 8 / 8

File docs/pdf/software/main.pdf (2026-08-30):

Private Reserve · DIN controller · first draft

# Main

Live door state. The spec name is Standard Operating Mode. The operator label is Main. This is the default screen after boot and after wake from a blanked panel.

Draft. Pixel layout: UI/index.html (320 × 170). LCD and web draw the same state tree. The web keypad sits to the right of the panel. Full chrome: overview figure 1 and figure 9 below.

Needs setup blocks automatic motion. Until origin, markers, and an armed obstruction table exist, hall and rocker triggers stay off. The header reads NEEDS SETUP. The hero is a red POSITION UNKNOWN banner. Run Calibration.

### 1. Live screen chrome

Every live Main state uses the same regions. A latched fault replaces the hero and the current meter with a red banner. GPIO numbers, duty, phase timers, bin index, and drift live in Diagnostics, not here.

Region | What it shows
Header left | MAIN when setup is complete, or NEEDS SETUP.
Header right | Link state. Green pip and STA plus the IP, or amber pip and AP plus the SoftAP name (default PrivateReserve). The join password is not in the header.
Hero | Current action in the largest type. A latched fault replaces this with a red banner.
Current | Live amps against the learned trip for the bin the door is in. The red tick is that bin’s trip. The hard 2.50 A ceiling is the right edge. Hidden when a fault banner occupies the hero.
Travel | Share of the measured span in AS5600 counts. Ticks are the two near-end markers. Outer ends are open-seated and closed-seated. The grey line under the bar is percent and counts, or position unknown.
Tiles | Bottle key, open marker, close marker, shaft rev/s. The close-marker title clips to CLOSE MARK… on the 320-pixel panel.
Footer | TURN menu · PRESS menu. Either gesture opens the mode menu.
Private Reserve · Software User Manual · Main | 1 / 15

### 1.1 Needs setup — position unknown

Default after power loss until guided calibration finds origin. Automatic hall and rocker triggers stay off.

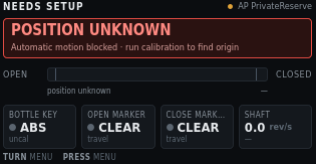
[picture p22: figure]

Figure 1. Main · needs setup. Position unknown. SoftAP serving.

Private Reserve · Software User Manual · Main | 2 / 15

On screen | Meaning
NEEDS SETUP | Header left. Origin, markers, or the calibration format is invalid. Automatic motion is blocked.
Amber pip + AP PrivateReserve | Header right. Station join failed or SSID is empty. Fallback SoftAP is serving. Default name is PrivateReserve. Default join password is reserved. The header does not show the password. Read it on Settings → Network or Diagnostics → Network. Then open http://192.168.4.1/.
POSITION UNKNOWN | Red banner title. The AS5600 is single-turn. After reset the firmware does not know which turn the door is on.
Automatic motion blocked · run calibration to find origin | Banner detail. Hall and rocker triggers stay disabled until Calibration finds origin.
OPEN / CLOSED | Travel ends. Open is the left of the bar. Closed is the right.
Empty travel track, grey thumb | No fill and no marker ticks in this state. Position is not known, so the bar cannot show a share of span.
position unknown | Left scale under the bar. Replaces percent until origin exists.
— (right of the scale) | Count field. Empty because there is no origin to accumulate from.
BOTTLE KEY · grey pip · ABS · uncal | Hall reads absent. Key levels are not yet captured, so the grey line is uncal instead of an ADC count.
OPEN MARKER · grey pip · CLEAR · travel | Open near-end switch is not made. travel means the door is not at that end (or the end is unknown).
CLOSE MARK… · grey pip · CLEAR · travel | Close near-end switch is not made. Title is Close marker. The tile clips the word.
SHAFT · 0.0 rev/s · — | Motor at rest. Direction dash means no rotation this cycle.
TURN menu · PRESS menu | Either gesture opens the mode menu. Position Unknown is not an acknowledge-away fault.
Private Reserve · Software User Manual · Main | 3 / 15

### 1.2 Opening

Setup is complete. The bottle key went absent. The door is in cruise toward open.

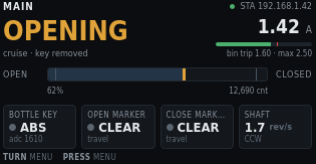
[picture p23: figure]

Figure 2. Main · opening. Cruise, key removed.

Private Reserve · Software User Manual · Main | 4 / 15

On screen | Meaning
MAIN | Header left. Setup is complete. Automatic motion is allowed.
Green pip + STA 192.168.1.42 | Header right. ESP32 joined site Wi-Fi as a station. HTTP is on this address.
OPENING (amber) | Hero. Current action. Amber means the motor is moving.
cruise · N in left | Motion phase and remaining throw to the destination marker. The bottle key is absent.
1.42 A | Live motor current from the ACS712 after scale.
Green fill on the current bar | Live amps as a share of the 2.50 A hard ceiling. Green because 1.42 A is under this bin’s trip.
Red tick on the current bar | This bin’s learned trip (1.60 A). Not the hard ceiling.
bin trip 1.60 · max 2.50 | Numeric trip for the bin the door is in, then the compile-time ceiling at the right edge of the bar.
OPEN / CLOSED | Travel ends.
Blue fill to 62%, yellow thumb, two marker ticks | Door is 62% of the measured span toward closed. Marker ticks sit near each end. Neither tick is hot.
62% | Share of measured span. Percent is the headline. Counts sit on the right.
12,690 cnt | AS5600 counts from the open origin.
BOTTLE KEY · grey pip · ABS · adc 1610 | Key absent. Raw ADC is the diagnostic value for this tile.
OPEN MARKER · grey pip · CLEAR · travel | Open switch not made. Door is in mid travel.
CLOSE MARK… · grey pip · CLEAR · travel | Close switch not made.
SHAFT · 1.7 rev/s · CCW | Shaft speed and direction. On this build CCW is toward open.
TURN menu · PRESS menu | Open the mode menu. There is no Stop on Main.
Private Reserve · Software User Manual · Main | 5 / 15

### 1.3 Idle — closed and seated

Move finished. Seal is loaded. Motor is at rest.

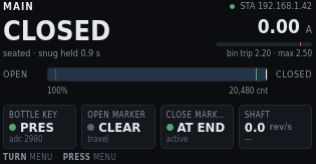
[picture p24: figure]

Figure 3. Main · idle closed. Seated, snug held.

Private Reserve · Software User Manual · Main | 6 / 15

On screen | Meaning
MAIN | Header left. Setup complete.
Green pip + STA 192.168.1.42 | Station Wi-Fi, HTTP on this IP.
CLOSED | Hero. Door is at the closed-seated end. White, not amber, because the motor is idle.
seated · snug held 0.9 s | How the stop was held. Snug is current-rise seating past the close marker. 0.9 s is hold time this cycle.
0.00 A | Motor current at rest.
Empty current bar, red tick near the right | Live fill is zero. The tick is this bin’s trip (2.20 A).
bin trip 2.20 · max 2.50 | Closed-end bin trip, then the 2.50 A ceiling.
OPEN / CLOSED | Travel ends.
Fill to the closed end, close-marker tick hot | Door is at 100% of span. The close-marker tick is active because the switch is made.
100% · 20,480 cnt | At closed seated. Counts include travel past the close-marker edge.
BOTTLE KEY · green pip · PRES · adc 2980 | Bottle in the recess. Green pip means present on this polarity.
OPEN MARKER · grey pip · CLEAR · travel | Open switch not made.
CLOSE MARK… · green pip · AT END · active | Close switch is made. AT END is the cooked label. active is the raw switch state.
SHAFT · 0.0 rev/s · — | At rest. No rotation this cycle.
TURN menu · PRESS menu | Open the mode menu.
Private Reserve · Software User Manual · Main | 7 / 15

### 1.4 Closing — creep and snug

Past the close marker. The profile has left cruise and is seating the seal.

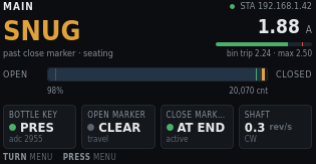
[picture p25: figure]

Figure 4. Main · snug. Past close marker, seating.

On screen | Meaning
MAIN | Header left.
Green pip + STA 192.168.1.42 | Station Wi-Fi.
SNUG (amber) | Hero. Creep-and-seat phase after the close marker. Motor is still moving.
past close marker · seating | Why snug is showing. Operational snug is a current-rise stop, not a home.
1.88 A | Live current. Seal loading raises amps above cruise.
Green fill, red tick near the right | 1.88 A is still under this bin’s 2.24 A trip.
bin trip 2.24 · max 2.50 | Near-closed bin trip, then the hard ceiling.
OPEN / CLOSED | Travel ends.
Fill at 98%, close-marker tick hot | Almost seated. Close switch is made.
98% · 20,070 cnt | Share of span and counts from origin.
BOTTLE KEY · green pip · PRES · adc 2955 | Bottle present. Close was commanded with the key in.
OPEN MARKER · grey pip · CLEAR · travel | Open switch not made.
CLOSE MARK… · green pip · AT END · active | Close switch made.
SHAFT · 0.3 rev/s · CW | Slow creep toward closed. CW is toward closed on this build.
TURN menu · PRESS menu | Open the mode menu. The move ends at seated, a reverse trigger, a fault, or obstruction handling.
Private Reserve · Software User Manual · Main | 8 / 15

### 1.5 Obstruction — reversing

Close current crossed the bin trip. Firmware reversed toward open. Obstruction handling outranks ordinary commands.

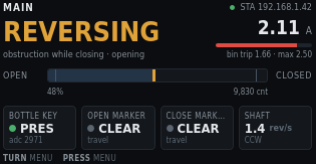
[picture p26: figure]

Figure 5. Main · reversing. Obstruction while closing.

Private Reserve · Software User Manual · Main | 9 / 15

On screen | Meaning
MAIN | Header left.
Green pip + STA 192.168.1.42 | Station Wi-Fi.
REVERSING (amber) | Hero. Close obstruction. The door is opening to clear the path.
obstruction while closing · opening | Cause and the commanded direction now.
2.11 A | Live current. Above this bin’s trip, so the fill is red.
Red fill past the red tick | Live amps exceeded the learned trip (1.66 A). That is why reverse started.
bin trip 1.66 · max 2.50 | Mid-travel bin trip, then the hard ceiling. Reverse used the learned trip, not the 2.50 A ceiling.
OPEN / CLOSED | Travel ends.
Fill at 48%, neither marker hot | Mid travel. Both switches clear.
48% · 9,830 cnt | Position when reverse is in progress.
BOTTLE KEY · green pip · PRES · adc 2971 | Bottle still present. Close had been the automatic command.
OPEN MARKER · grey pip · CLEAR · travel | Not yet at the open end.
CLOSE MARK… · grey pip · CLEAR · travel | Not at the close end.
SHAFT · 1.4 rev/s · CCW | Opening. CCW toward open on this build.
TURN menu · PRESS menu | Open the mode menu. Reverse still owns the motor until it finishes or faults.
Private Reserve · Software User Manual · Main | 10 / 15

### 1.6 Fault — second close obstruction

A second close obstruction in the retry window latches a fault. The current meter leaves the panel. PRESS acknowledges when firmware allows it.


Figure 6. Main · latched obstruction fault. Press to acknowledge.

On screen | Meaning
MAIN | Header left. Setup is still complete. This is a motion fault, not Needs Setup.
Green pip + STA 192.168.1.42 | Station Wi-Fi.
OBSTRUCTION ×2 | Red banner title. Second close obstruction. The door stopped instead of reversing again.
Repeated close obstruction · press knob to acknowledge | Banner detail. PRESS clears this banner when the firmware allows it. TURN still opens the mode menu.
OPEN / CLOSED | Travel ends. The current meter is hidden while the fault banner occupies the hero.
Red thumb at 44% | Position where the second trip stopped the door. Red track because this is a fault state.
44% · 9,010 cnt | Stopped position.
BOTTLE KEY · green pip · PRES · adc 2969 | Bottle still present.
OPEN MARKER · grey pip · CLEAR · travel | Not at the open end.
CLOSE MARK… · grey pip · CLEAR · travel | Not at the close end.
SHAFT · 0.0 rev/s · — | Motor stopped after the fault.
TURN menu · PRESS menu | On this fault, PRESS acknowledges. TURN opens the mode menu. Position Unknown is the fault that cannot be acknowledged away.
Private Reserve · Software User Manual · Main | 11 / 15

### 2. Mode menu

TURN or PRESS on the live Main screen opens this list. Five items. TURN scrolls. PRESS opens. HOLD returns to the live Main screen.

### 2.1 Five destinations


Figure 7. Mode menu. Five items. Calibration pip is amber because setup is still needed.
Documentation is the fifth row.
On screen | Meaning
MODE | Header left. Same screen family as Main. Not a fourth operating mode.
Green pip + STA 192.168.1.42 | Header right. Same link state as Main.
Blue highlight + left bracket on Main | Selected row. PRESS opens the live Main screen.
Green pip + Main + DOOR | Live door. Value column is the subject of that page.
Green pip + Diagnostics + I/O | Opens the diagnostic menu.
Amber pip + Calibration + NEEDED | Opens the stage list. Amber pip and NEEDED mean origin or later stages are missing. After a full save this row shows green and a status such as armed.
Green pip + Settings + NVS | Opens settings groups. Value is NVS when stored, or unsaved when staged edits exist. If the motor is running, Settings Locked instead.
Green pip + Documentation + GitHub | Opens the Documentation page. QR code for the public project URL.
TURN scroll | Move the highlight.
PRESS open | Enter the highlighted item.
HOLD back | Return to the live Main screen without changing mode.
Private Reserve · Software User Manual · Main | 12 / 15

Web nav tabs send the same jumps: Main, Calibration, Diagnostics, Settings, Docs. They turn the LCD on if it was blank. Settings is a heavier first paint (group list plus a possible NVS write when leaving jog); the firmware feeds the watchdog on that path so HTTP does not die after the list shows.

### 2.2 Documentation

Not an operating mode. A read-only page from the mode menu. Header is DOC. The panel shows a QR code for the public project page and the same path as text. This page does not command the motor. PRESS does nothing. HOLD returns to the mode menu.


Figure 8. DOC. QR and path for the public GitHub page.

On screen | Meaning
DOC | Header left. Documentation page.
Green pip + STA 192.168.1.42 | Header right. Same link state as Main. Amber pip and AP when the fallback SoftAP is serving.
QR code (left) | Encodes https://github.com/KopperToolworks/PrivateReserve. Scan with a phone camera. The enclosure sticker uses the same URL.
github.com/KopperToolworks | Host, as text, if the QR is hard to scan.
PrivateReserve | Repository name.
source and docs | What the page holds. Source, operator docs, and enclosure notes.
scan to open | How to use the QR. On the web copy of this screen, a blue link labelled Open GitHub page opens the same URL. The full web chrome (tabs and keypad) is overview figure 1 and figure 9 below.
HOLD back | Return to the mode menu.
SCAN code | Footer hint. Not a knob gesture. PRESS on this page does nothing.

Pixel source: Main mockup (Documentation state). The enclosure sticker uses the same URL; see DIN/enclosure.md. The repo must stay public or the QR is useless.

Private Reserve · Software User Manual · Main | 13 / 15

### 3. Knob on Main

Gesture | Action
TURN or PRESS (live screen) | Open the mode menu.
PRESS on Documentation | No-op. The QR is the action.
HOLD on Documentation | Return to the mode menu.
PRESS on a latched fault that can be acknowledged | Clear the banner when the firmware allows it. Position Unknown is not an acknowledge-away fault. It needs calibration.
Hall / rocker | Open or close when setup is ready. Edges, not hold-to-run. Open wins if both rocker throws hit in the same cycle.

There is no Stop on this screen. A move ends at destination, snug, a reverse trigger, a fault, or obstruction handling.

### 4. Web page

The LCD shows only the 320 × 170 panel. The phone page adds tabs on top and a keypad on the right. Use landscape. The shell scales to the viewport. There is no application login.

Figure 9. Full web UI on Documentation. Same chrome on every page. Overview figure 1 names every chrome label.

Private Reserve · Software User Manual · Main | 14 / 15

Chrome | Command
Tabs: Main · Calibration · Diagnostics · Settings · Docs | Jump to that page. Active tab is white. They turn the LCD on if it was blank.
Left circular arrow | TURN − (matches CCW on the physical knob)
Right circular arrow | TURN + (matches CW on the physical knob)
Large Return arrow | PRESS
Wide left arrow | HOLD back

On Documentation the web panel also shows Open GitHub page. That link is not on the LCD. PRESS on this page does nothing. HOLD returns to the mode menu.

### 5. Related

Software overview
Settings — clear station Wi-Fi and reboot Board A — terminals named on the tiles

This page is a chapter of the Software User Manual.

Private Reserve · Software User Manual · Main | 15 / 15

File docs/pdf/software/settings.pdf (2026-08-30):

Private Reserve · DIN controller · first draft

# Settings

Not a fourth operating mode. A menu reached from Main, the same way as Calibration and Diagnostics. Header prefix is SET ·. Motion is idle while values are edited. Service holds the destructive actions: erase tables, restore defaults, clear calibration, clear station Wi-Fi, and reboot the controller.

Draft. Pixel layout: UI/settings.html. NVS names and defaults: T-Display-S3_Firmware_Config.md.

Never write NVS while the motor runs. If you open Settings during a move, the panel shows SETTINGS LOCKED. Pending edits stay in RAM. Retry when idle. A profile or travel change that invalidates learned tables says so on its own screen and again on confirm.

Private Reserve · Software User Manual · Settings | 1 / 15

### 1. Groups

Grouped by effect, not by NVS layout. The count on the right is how many values sit in each group. An amber pip marks a group that holds an unsaved change. Six rows fit. Service is the seventh row, off this shot until you TURN.

The web Settings tab paints that group list from /api/state, then keeps polling. Leaving jog to open Settings can write NVS on the same HTTP request as the first paint. The 3 s task watchdog used to miss those stretches, so the list appeared once and the controller stopped answering. Firmware now resets the watchdog around NVS, HTTP, and LCD draw, and it will not walk an unterminated NVS string forever.


Figure 1. SET · groups. Three unsaved changes. Motion profile selected.

Private Reserve · Software User Manual · Settings | 2 / 15

On screen | Meaning
SET · groups | Header left. Settings root.
3 unsaved ▾ | Header right. Three staged field edits. The triangle means more groups below.
Amber pip + highlight + Motion profile + 4 VALUES | Selected. Door pace, min duty, creep, jog. Amber when pace is staged (invalidates tables).
Green pip + Travel and markers + 6 VALUES | Caps, probe tolerance, resync drift. Some rows open a locked derived page.
Amber pip + Obstruction detection + 5 VALUES | Inrush skip, snug amps, envelope knobs. Amber because this group also holds a staged edit in this example.
Green pip + Triggers and debounce + 3 VALUES | Bottle-key polarity and switch debounce. Saving polarity re-arms from the current sensor level. It does not command a move.
Green pip + Display and knob + 3 VALUES | Display timeout (minutes, default 5), HOLD min ms, HOLD max ms.
Green pip + Network + 5 VALUES | STA SSID, STA password, join timeout, AP name, AP password. Station password is web-only. Fallback AP password is shown in clear (default reserved). This row is clipped at the bottom of the panel. A 4-byte NVS layout shift used to advertise SoftAP as ateReserve (the tail of PrivateReserve). Boot now restores the default name and password when that suffix is all that remains, then rewrites NVS.
Service and defaults + 5 ACTIONS (off-screen) | Seventh group. TURN to it. Destructive. Figure 11. Clear station Wi-Fi is the fourth action; Reboot controller is the fifth. PRESS twice.
TURN scroll | Move the highlight. Window the list.
PRESS open | Enter the highlighted group.
HOLD exit | Return to Main. Staged edits stay in RAM until Review saves or discards them.
Private Reserve · Software User Manual · Settings | 3 / 15

### 2. Motion profile group

A value list, not a form. Pending edits show the new value in amber next to the stored one. Decelerate is the seventh row, off this shot.


Figure 2. SET · motion. Cruise duty staged 512 → 544.

On screen | Meaning
SET · motion | Header left.
7 values | Header right. Count in this group.
Highlight + Door pace | Selected. Gentle…Brisk slider, speed-vs-throw graph, About X s and peak g. Changing pace invalidates both learned tables.
Minimum moving duty · 64 | Floor while the profile is moving. Below this the motor may not break away.
Creep duty · 96 | Duty for marker seeks, snug, and short calibration moves.
Jog duty · 96 | 10-bit duty for both diagnostic jog pages. Those pages edit it as 5–25%. Time jog also edits step as 200–1000 ms. Position jog edits step as 16–512 counts.
Accelerate · 3000 MS | Time to climb from moving floor to cruise. Changing it invalidates tables.
Cruise time · 6000 MS | Time at cruise duty. Changing it invalidates tables. Clipped at the bottom of this shot.
Decelerate · 3000 MS (off-screen) | Seventh value. TURN to it. Time to drop from cruise to creep. Changing it invalidates tables.
TURN scroll · PRESS edit · HOLD back | Move, open the edit screen, or return to groups.
Private Reserve · Software User Manual · Settings | 4 / 15

### 3. Edit — cruise duty

The sharpest setting on the controller. Range, default, and step are on the panel. The consequence line is stated before the edit is accepted.


Figure 3. SET · cruise duty. Pending 544. Invalidates both tables.

On screen | Meaning
SET · cruise duty | Header left. Field name.
motion 1/7 | Header right. First field in the motion group.
544 with caret, blue box | Pending value. TURN changes it.
duty counts, 10-bit | Unit. Same 0–1023 scale as the PWM diagnostic.
was 512 · 53% of 1023 · 15 kHz fixed | Stored value, percent of full scale, and the compile-time carrier. 15 kHz is not editable.
Blue fill on the range bar, white tick | Fill is the pending value. The tick is the default (512).
min 128 · default 512 · max 768 | Allowed range and factory default. Max is below 1023 so cruise cannot sit on the rail.
step per detent · 8 counts | How much TURN changes the pending value.
estimated stroke time · 12.0 s → 11.4 s | Advisory. Faster cruise shortens the move. Not a safety limit.
invalidates · both learned tables (amber) | Accepting this drop both envelopes to stale. Until a relearn, trip is the 2.50 A ceiling only.
TURN adjust · PRESS accept · HOLD cancel | Change, keep the pending value (then confirm), or restore 512.
Private Reserve · Software User Manual · Settings | 5 / 15

### 4. Confirm — consequence of the edit

Shown when an accepted edit invalidates learned data. Dropping to the hard ceiling is a real reduction in protection, so it is spelled out and needs a second press.


Figure 4. SET · confirm. Cruise duty will stale both obstruction tables.

On screen | Meaning
SET · confirm | Header left.
cruise duty | Header right. Which field triggered this gate.
RELEARN REQUIRED | Amber banner title.
Changing the profile invalidates both obstruction tables | Banner detail. Door pace does this (same as the old cruise/accel/decel knobs).
Amber pip + Empty-rack table + ARMED → STALE | Empty envelope is in service now. After this save it will not be.
Amber pip + Loaded-rack table + STALE → STALE | Already stale. Stays stale.
Red pip + Until relearn, trip is + 2.50 A CEILING ONLY | Protection drops to the hard ceiling. Main still runs, with less discrimination.
PRESS accept change | Keep the pending cruise duty. Tables mark stale on Review save, not on this press alone.
HOLD keep 512 | Drop the pending edit. Stored 512 stays.
Private Reserve · Software User Manual · Settings | 6 / 15

### 5. Edit — display timeout

A benign value, shown for contrast. No consequence line, no confirm step. Units are minutes because that is how an operator thinks about a screen going dark.


Figure 5. SET · display timeout. Default 5 minutes. Invalidates nothing.

On screen | Meaning
SET · display timeout | Header left.
display 1/3 | Header right. First of three Display and knob fields.
5 with caret | Pending minutes of idle before blanking.
minutes of idle | Unit on the panel. Firmware stores milliseconds.
stored 300 000 ms · 0 disables blanking | NVS value for 5 minutes. Zero means the panel stays on.
Range bar, min 1 · default 5 · max 60 | Allowed minutes. Default matches the factory 300000 ms.
step per detent · 1 minute | TURN step.
wakes on · knob turn · knob press · GPIO14 | What resets the timer and what wakes a blanked panel. Web commands also reset it. Wake returns to Main.
invalidates · nothing | This field does not stale calibration or tables. Dim on purpose.
TURN adjust · PRESS accept · HOLD cancel | Same edit gestures as cruise duty. No confirm step after PRESS.
Private Reserve · Software User Manual · Settings | 7 / 15

### 6. Edit — trigger polarity

An enumerated choice, so it is a two-item pick list rather than a number. Saving re-arms the trigger from the level the sensor is reading now, which is why that line is on the screen.


Figure 6. SET · key polarity. Default: absent opens. Key reads PRESENT now.

On screen | Meaning
SET · key polarity | Header left.
triggers 1/3 | Header right. First of three Triggers and debounce fields.
Green pip + highlight + Bottle absent opens the door + DEFAULT | Selected choice. Handbook polarity. Place the bottle to close.
Grey pip + Bottle present opens the door | Inverted polarity. Use only if this cabinet is wired that way.
key reads now · PRESENT · adc 2 971 | Live cooked state and raw ADC, so you can see what re-arm will start from.
on save · re-arm from current level, no move | Firmware adopts the new polarity from the present reading. It does not command open or close.
client handbook says · place the bottle to open (amber) | Published client instruction. Compare it with the selected row before you accept. Absent-opens means remove the bottle to open. Present-opens means place the bottle to open.
TURN choose · PRESS accept · HOLD cancel | Move the highlight, stage the choice, or keep the previous polarity.
Private Reserve · Software User Manual · Settings | 8 / 15

### 7. Network group

Text entry through one knob is a trap, so the LCD shows the values and points at the web page. The station password is masked. The fallback AP password is shown in clear (default reserved) so a phone can join PrivateReserve before /wifi exists. Then open http://192.168.4.1/. The web View of this screen adds a clickable Set SSID and password link, the same idea as Docs adding Open GitHub page. That form is hosted by the controller at /wifi and is not drawn on the LCD. Scan takes a few seconds. The page stays live. The screen states that the web interface has no login. To drop the stored STA network, do not edit this list: use Service → Clear station Wi-Fi, then reboot.


Figure 7. SET · network. Station password masked. Fallback AP password in clear. No application login.

Private Reserve · Software User Manual · Settings | 9 / 15

On screen | Meaning
SET · network | Header left.
5 values | Header right.
Station SSID · house-iot | Stored STA network name. Shown in clear.
Station password · ******** (web only) | Masked. The LCD cannot edit it. On the web View of this screen, open Set SSID and password. That is a separate page at /wifi on the controller, with a phone keyboard and a Scan list. Scan takes a few seconds; the page stays live. It is not on the LCD.
Join timeout · 15 000 ms | How long STA join may run before SoftAP starts. This is a number. PRESS can edit it from the knob.
Fallback AP name · PrivateReserve | SoftAP SSID when STA is empty or join fails. Default name is PrivateReserve. If NVS was shifted by four bytes, this used to load as ateReserve; boot restores the default and rewrites the blob.
Fallback AP password · reserved | Shown in clear. You need this before the web page exists. Default is reserved. Empty means an open AP. Change it later on /wifi.
Amber line: No login on the web page. Anyone on this network can move the door. | HTTP is port 80 with no application login. Do not expose that LAN.
TURN scroll | Move among rows.
PRESS edit numbers | Edit join timeout (and other numeric fields). SSID and passwords do not open a knob editor. On the web, a blue Set SSID and password link opens /wifi. To drop the stored STA network, use Service → Clear station Wi-Fi.
HOLD back | Return to groups.
Private Reserve · Software User Manual · Settings | 10 / 15

### 8. Derived and locked values

Read-only by design. Counts-per-inch came from a measured span and a typed stroke. The ceiling and the PWM carrier are hardware facts. Showing them with a lock stops somebody hunting for an edit screen.


Figure 8. SET · derived · locked. Recalibrate to change these.

On screen | Meaning
SET · derived · locked | Header left.
read only | Header right. No edit affordance.
Measured span · 20 180 cnt · from stage 4 | Close-marker actuation minus origin. Dim because it is not editable here.
Counts per inch · 631 · derived from stroke | Display scale only. Never a seek cap.
Seated position · 20 348 cnt · stage 5 | Closed seated counts.
Hard current ceiling · 2.50 A · compile-time | Not an NVS setting. Firmware constant.
PWM carrier · 15 kHz · 10-bit | Not an NVS setting. Hardware/firmware fact.
Green line: Recalibrate to change these. No settings screen can adjust them. | Span and seated change only through Calibration. Ceiling and carrier do not change in the field.
HOLD back | Return. There is no PRESS.
Private Reserve · Software User Manual · Settings | 11 / 15

### 9. Review and save pending changes

The single write point, mirroring Calibration review. It lists every staged change with old and new value. It will not write while the motor is running.


Figure 9. SET · review. Three field edits plus the table-stale side effect.

On screen | Meaning
SET · review | Header left.
3 changes | Header right. Three field writes in this set. The side-effect row is extra.
READY TO SAVE (green) | Hero. Motor idle, current decayed.
motor idle · current decayed | Write precondition. Same rule as Calibration review.
Amber pip + Cruise duty + 512 → 544 | First staged write. Amber because it invalidates tables.
Green pip + Display timeout + 5 → 8 MIN | Second staged write. Benign.
Green pip + Switch debounce + 25 → 30 MS | Third staged write.
Amber pip + Side effect: both tables → stale | Not a field you typed. Consequence of cruise duty. Named so it cannot be missed.
PRESS save all | One NVS write of the remaining rows.
TURN drop one | Remove the highlighted row from this set. It stays at the stored value.
HOLD discard | Drop the whole set. Stored NVS is unchanged.
Private Reserve · Software User Manual · Settings | 12 / 15

### 10. Edit blocked — motor busy

A defined refusal, not an error. Configuration cannot change under a running profile or an active calibration stage. The screen names which one is holding the lock.


Figure 10. SET · blocked. Door closing. Three pending edits kept in RAM.

On screen | Meaning
SET · blocked | Header left.
no write | Header right. This screen will not commit NVS.
SETTINGS LOCKED | Red banner title.
Door is closing · configuration writes need an idle motor | Banner detail. Why, and the rule.
holder · automatic close · cruise | Which activity owns the motor. Could also name a calibration or jog step.
pending changes · 3 kept in memory | Staged edits survive. They are not discarded by the lock.
retry · when motion completes or faults | Open Settings again after idle. Review can then save.
HOLD back | Leave. No PRESS. There is nothing to accept.
Private Reserve · Software User Manual · Settings | 13 / 15

### 11. Service and defaults

Destructive actions live together, away from ordinary edits. Each states its blast radius. PRESS confirm twice. Motor must be idle. Full factory erase is USB-only. It is not on this menu.


Figure 11. SET · service. Five actions. Erase tables selected. Confirm twice. Clear station Wi-Fi and Reboot controller are the fourth and fifth rows.

On screen | Meaning
SET · service | Header left.
5 actions | Header right. Not values. Actions.
Red pip + highlight + Erase obstruction tables + BOTH | Selected. Drops empty and loaded envelopes. Origin stays. Hard ceiling until relearn.
Amber pip + Restore setting defaults + KEEPS CALIBRATION | Settings struct reset. Keeps calibration. Keeps Wi-Fi strings.
Red pip + Clear calibration and origin + FORCES SETUP | Main shows Needs Setup. Automatic motion blocks until Calibration runs again.
Amber pip + Clear station Wi-Fi + SOFTAP AFTER REBOOT | Zeros stored STA SSID and password. Fallback AP name and password stay. The live STA session stays until reboot. Next boot skips STA and starts SoftAP.
Amber pip + Reboot controller + NOW | Stops PWM and resets the ESP32. Same as a power cycle. Motion does not resume. PRESS twice, motor idle.
selected action · erases both envelopes · hard ceiling until relearn | Blast radius of the highlighted row, restated under the list.
PRESS confirm twice | First PRESS arms. Second PRESS runs. HOLD at either step aborts. TURN after the first PRESS cancels the arm.
HOLD back | Return to groups without running an action.
Private Reserve · Software User Manual · Settings | 14 / 15

### 12. Station Wi-Fi cleared

Shown after Clear station Wi-Fi runs. The write is already in NVS. PRESS reboots now so SoftAP can start. HOLD returns to Settings if you want to reboot later from Service.

Figure 12. SET · wifi. Station SSID empty. PRESS reboots. HOLD leaves this session on the old STA address.

On screen | Meaning
SET · wifi | Header left.
reboot | Header right. The change is stored. SoftAP starts on the next boot.
WIFI CLEARED | Warn banner. Station SSID and password are empty.
PRESS reboot · SoftAP on next boot | This session can stay on the old STA address until you PRESS or power-cycle.
Station SSID · (empty - AP only) | Boot will skip STA join.
Fallback AP name · PrivateReserve | Unchanged. Join this AP after reboot, then set a new SSID on the web.
Join password · reserved | WPA2 PSK for that AP. Type it on the phone. Shown here because the web page is not reachable until you join.
After reboot · join AP, then set SSID on the web | SoftAP starts. Then open http://192.168.4.1/wifi. The live STA link, if any, stays until this reboot.
PRESS reboot | Stops PWM and resets the ESP32. One PRESS. Motor must be idle.
HOLD back | Return to Settings groups without rebooting.

### 13. Related

Software overview — full web UI, figure 1 Documentation — GitHub QR

This page is a chapter of the Software User Manual.

Private Reserve · Software User Manual · Settings | 15 / 15

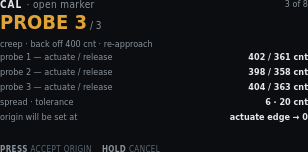
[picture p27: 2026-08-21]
docs/html/shots/cal-07.png

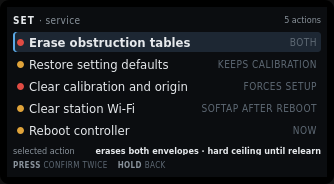
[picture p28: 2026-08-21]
docs/html/shots/set-11.png

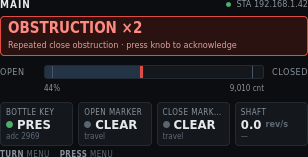
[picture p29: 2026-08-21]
docs/html/shots/main-06-fault.png

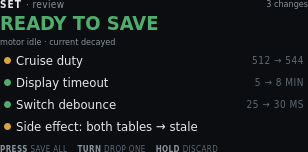
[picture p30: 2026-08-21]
docs/html/shots/set-09.png

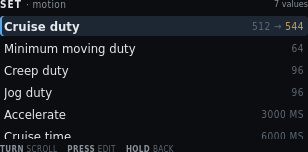
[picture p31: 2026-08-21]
docs/html/shots/set-02.png

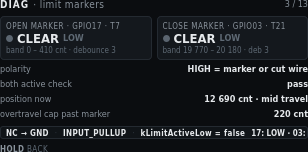
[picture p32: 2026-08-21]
docs/html/shots/diag-04.png

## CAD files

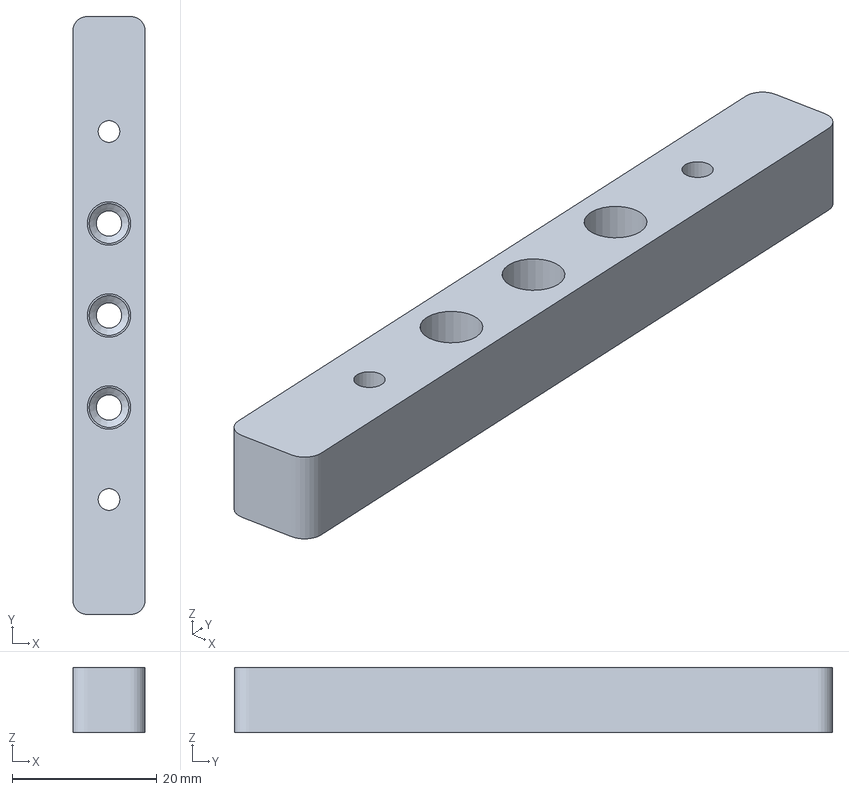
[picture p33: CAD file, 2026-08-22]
models/Dual PermaProto Standoff-Body.3mf
10.0 x 82.5 x 9.00 mm

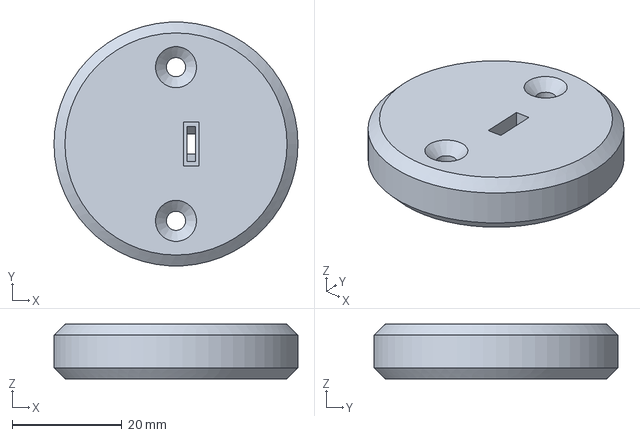
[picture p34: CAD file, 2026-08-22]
models/Sensor Puck - v03.3mf
44.5 x 44.4 x 10.0 mm

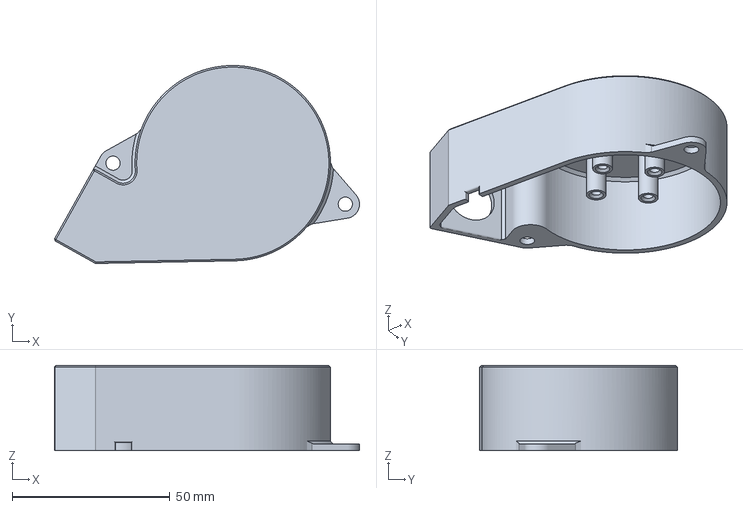
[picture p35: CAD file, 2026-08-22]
models/Rotary Encoder Cover10-Body.3mf
96.8 x 62.8 x 27.0 mm

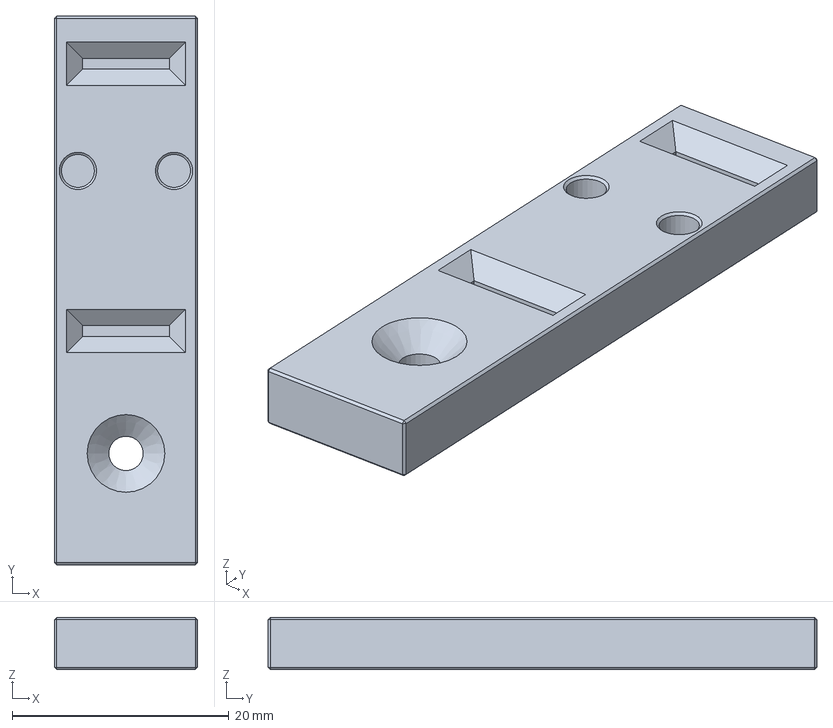
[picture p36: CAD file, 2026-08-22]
models/Current Load Sensor Mount - v3.3mf
13.2 x 50.7 x 4.81 mm

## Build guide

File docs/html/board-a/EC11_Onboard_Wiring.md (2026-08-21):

# Board A — EC11 on-board wiring

The **EC11** menu encoder mounts on the Board A Perma-Proto carrier, to the
**right** of the T-Display-S3 (opposite USB-C). It is **not** wired through
screw terminals.

Signals run as **short on-board leads** from the EC11 breakout to the
T-Display-S3 **bottom** header pins. GPIO11, GPIO12, and GPIO13 never leave
the carrier on field cables.

**Terminal map (T1–T24):** [`index.html`](index.html)  

---

## EC11 → T-Display-S3

View with the display facing you and USB-C on the left. The bottom header uses
the pinout **LEFT** row (pin 12 nearest USB).

| EC11 breakout | T-Display header | GPIO | Net |
|---|---|---|-----|
| **CLK** | LEFT GPIO11 | **GPIO11** | Quadrature A |
| **DT** | LEFT GPIO12 | **GPIO12** | Quadrature B |
| **SW** | LEFT GPIO13 | **GPIO13** | Push (active-low) |
| **`+`** | LEFT or RIGHT **3V** | `+3V3_TDISPLAY` | 3.3 V only (breakout 10 kΩ pull-ups) |
| **GND** | header **GND** | `MCU_GND` | Common return |

Do not use **5 V** on these GPIOs. The breakout **`+`** pin expects 3.3 V.

On-board jumper routing (Perma-Proto rows/columns) is documented separately.
This page only records **which header pins** the encoder uses.

---

## Screw terminals T17–T19 are NC

Three bottom-edge screw terminals (**T17**, **T18**, **T19**) sit in the
same left-to-right index as GPIO13, GPIO12, and GPIO11. On the as-built
carrier they are **not connected**. The EC11 wires go directly to the
T-Display header, not to those blocks.

| Terminal | Header column (display-up) | As-built |
|---|---|---|
| **T17** | LEFT GPIO13 | NC — EC11 **SW** is on-board from the header |
| **T18** | LEFT GPIO12 | NC — EC11 **DT** is on-board from the header |
| **T19** | LEFT GPIO11 | NC — EC11 **CLK** is on-board from the header |

Do not land field cables on T17–T19 expecting encoder signals.

---

## Related

- [`index.html`](index.html) — Board A placement and screw-terminal table

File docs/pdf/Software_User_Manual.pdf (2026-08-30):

Private Reserve · DIN controller

# Software User Manual

Operator screens for production image tdisplay_s3_prod on the LilyGo T-Display-S3 (Board A).

The LCD and the phone web page share one controller state.

### 1. Overview 2. Main 3. Calibration 4. Diagnostics 5. Settings

Private Reserve · Software User Manual | 1 / 81

Private Reserve · DIN controller · first draft

# Software — operator UI

Production image tdisplay_s3_prod on the LilyGo T-Display-S3 (Board A). The LCD and the phone web page share one controller state. The EC11 knob, the web keypad, the rockers, and the bottle-door key all go through one command arbiter.

Draft. These pages describe the operator screens as built. Each option has a 320 × 170 panel shot. Every label on that shot is named in a field table on Main, Calibration, Diagnostics, and Settings. The web page adds tabs and a keypad; figure 1 is a full-chrome example. Pixel source: UI mockups. Motion, obstruction, and NVS names remain specified in Production_Software.md and T-Display-S3_Firmware_Config.md.

No application login. Anyone who can reach the controller on the joined LAN, or join its fallback SoftAP, can monitor, configure, and command the door. HTTP is port 80. Do not expose that network to the public internet.

### 1. Surfaces

View the LCD with USB-C on the left and the EC11 on the right. Firmware uses Arduino_GFX rotation 3. The logical panel is 320 wide by 170 tall. Origin (0, 0) is the operator-facing top-left.

The web page is the same state tree plus chrome the LCD does not have: tabs across the top, a keypad on the right that maps to the knob. Use it in landscape on a phone. The layout scales to fill the viewport without clipping. STA in the header means the ESP32 joined site Wi-Fi as a station. AP means the fallback SoftAP is serving.

Surface | Role
LCD (ST7789) | In-box operator panel. Off means GPIO38 backlight and GPIO15 panel power only. The MCU stays up.
Web (port 80) | Same screens. Tabs jump to Main, Calibration, Diagnostics, Settings, or Docs. Keypad on the right: turn − / +, press (Return), hold (back). Figure 1.
EC11 | TURN scroll or adjust. PRESS open or accept. HOLD back or cancel.
GPIO14 | On-board T-Display button. Same PRESS / HOLD window as the knob switch. Does not revert a recent turn.
Private Reserve · Software User Manual | 2 / 81

### 1.1 Full web page

On site Wi-Fi, open http://private-reserve.local or the STA address on port 80. On the fallback AP, join PrivateReserve with password reserved, then open http://192.168.4.1/. The LCD shows only the 320 × 170 panel. The web page adds tabs on top and a keypad on the right. This shot is Documentation. The panel inside the bezel is the same DOC screen as Main figure 8.

Figure 1. Full web UI in landscape. Tabs jump modes. The keypad maps to the EC11.

On screen | Meaning
Main · Calibration · Diagnostics · Settings · Docs | Top tabs. Jump to that page. They turn the LCD on if it was blank. Same destinations as the mode menu.
Docs in white | Active tab. Other tabs stay blue. The controller is on the Documentation page.
Bezel, 320 × 170 | The LCD panel. Same state tree as the physical display. Header here is DOC with STA 172.16.0.68.
QR · github.com/ · KopperToolworks/PrivateReserve | Public project page. The web copy adds a blue Open GitHub page link the LCD does not have.
Top pair, circular arrows | TURN − (CCW) and TURN + (CW). Same as the knob.
Tall Return arrow | PRESS. On Documentation this does nothing.
Wide left arrow | HOLD back. From Documentation this returns to the mode menu.

### 2. Knob map

HOLD fires once when the push has been down for ec11_hold_min_ms (default 400 ms). It does not wait for release. A shorter down is PRESS. Keeping the button down does not fire a second HOLD. ec11_hold_max_ms remains a setting; it does not delay the first HOLD.

Private Reserve · Software User Manual | 3 / 81

Pressing the knob can twist CLK/DT. If the highlight moved within ec11_press_revert_ms (100 ms) of an EC11 press, firmware restores the previous item, then handles PRESS. Rotation is ignored while SW is down.

On bottle key, limit markers, and override rockers, TURN selects one of two choices. The highlight stops at the end instead of wrapping. Extra clicks in that direction do nothing. One click moves once.

Gesture | Typical meaning | Web keypad
TURN − / + | Scroll a list or change a pending value | Top pair, circular arrows
PRESS | Open a screen, start a stage, or accept | Large Return arrow
HOLD | Back one screen, or cancel a live procedure | Wide left arrow

### 3. Command priority

Hard overcurrent and sensor or limit faults outrank all commands. Obstruction handling outranks ordinary commands. Among ordinary sources the order is EC11 → web → rocker → hall. At most one state-changing command runs per control cycle.

A live calibration or diagnostic-jog step owns the motor. Hall and rocker events may show on the screen. They cannot preempt that step. Main accepts hall and rocker triggers. Diagnostics has two jog pages. Jog by time is an EC11 (or web keypad) millisecond queue. PRESS while idle edits duty (5–25%) and time per detent (200–1000 ms). The encoder is not polled while that queue is moving. Jog by position queues relative shaft counts (no origin required) and runs only while the AS5600 and magnet are healthy. Opening that page polls the encoder. Current still draws as a live graph when the ACS712 is sampling.

There is no operator Stop on Main. Cancel exists only for a running calibration or diagnostic procedure. Cancel removes PWM, waits for current decay, leaves K1 unchanged, discards incomplete results, and returns to that mode’s menu.

Never write NVS while the motor runs. Config writes need an idle motor.

### 4. Boot, blanking, Wi-Fi

The screen is on at boot. Default idle timeout is 5 minutes (display_timeout_ms = 300000). Any EC11 turn or press, GPIO14, or web command resets the timer. Wake from a blanked panel returns to Main.

Calibration, diagnostics, faults, and any prompt that needs an answer inhibit blanking. A latched PositionUnknown on Main does not hold the panel on forever. That fault is the default boot state until origin is found.

STA join uses the stored SSID and password. If the SSID is empty or join fails, firmware starts a SoftAP.

Private Reserve · Software User Manual | 4 / 81

Fallback AP | Default
Name (SSID) | PrivateReserve
Join password | reserved (WPA2, eight characters)
Main page | http://192.168.4.1/
Set site Wi-Fi | http://192.168.4.1/wifi

Type the join password on the phone. Then open the main page. The LCD shows that password on Settings → Network, on Diagnostics → Network while SoftAP is up, and on the Wi-Fi-cleared result. Station (house) password stays masked. When STA joins, HTTP is on the STA address and http://private-reserve.local. The steel lid can block the onboard antenna. That note belongs on the network diagnostic screen.

Settings → Service can clear the stored station SSID and password. That write is immediate. The live STA session stays until reboot. After reboot, empty SSID skips STA and starts SoftAP. Fallback AP name and password stay. The same Service list can reboot the controller (PRESS twice). PRESS on the Wi-Fi-cleared result screen also reboots. See Settings figures 11 and 12.

No automatic resume after reset. A watchdog, brownout, operator reboot, or power cycle forces PWM off and cancels the prior command.

### 5. Modes

Default after boot is Main (Standard Operating Mode in the spec). Settings and Documentation are not extra operating modes. They are menu pages reached the same way as Calibration and Diagnostics. Motion is idle while settings are edited.

Private Reserve · Software User Manual | 5 / 81

Page | Header | Panel shots | What it is
Main | MAIN or NEEDS SETUP | 8 Live door. Mode menu: Main, Diagnostics, Calibration, Settings, | Documentation.
Calibration | CAL · … | 13 | Guided stages. Path-clear before any move. Save is one NVS write on Review.
Diagnostics | DIAG · … | 14 | One screen per input or output. Two jog pages own the motor: time (encoder unused) and position (healthy AS5600 required). PRESS edits duty % and step. Current is a live graph. Obstruction test owns the motor. Bottle key, limit markers, and override rockers can inject a cooked signal from PRESS.
Settings | SET · … | 12 | Staged edits. Review commits. Service actions are destructive and confirm twice, including reboot and clear station Wi-Fi.
Documentation | DOC | 1 | QR and URL for the public GitHub page. HOLD returns to the mode menu. PRESS does nothing.
Private Reserve · Software User Manual | 6 / 81

Entry screens for each mode:

Figure 2. Mode menu on Main. PRESS opens the highlighted item.


Figure 3. Calibration stage list. See Calibration for every stage.


Figure 4. Diagnostics menu. See Diagnostics for all twelve items.

Private Reserve · Software User Manual | 7 / 81


Figure 5. Settings groups. See Settings for edit, review, service, Wi-Fi clear, and reboot.

Figure 6. Documentation panel only. See Main · Documentation for every label on this panel. The full web chrome is figure 1.
Every label on these shots is named in the field table on the linked page.

### 6. Field I/O the screens name

Position is AS5600 counts from the open origin. Inches appear after stroke entry (open marker to close marker). Automatic moves use Door pace on remaining distance. The belt spring take-up is calibrated so a duty step is not treated as leaf motion. The three analog sensors stay independent.

Private Reserve · Software User Manual | 8 / 81

Name | Part | GPIO / Board A | Job
Bottle door key | 49E / SS49E | GPIO1, T23 | Magnet present or absent. Automatic open/close.
Shaft encoder | AS5600 | GPIO43/44, T10/T9 | Door position as accumulated counts. Diagnostics shows I²C ACK/NACK separately from magnet STATUS.
Current load | ACS712-05B | GPIO2, T22 | Motor current. Envelope and snug.
Open marker | NC switch | GPIO17, T7 | Near-end flag, open side.
Close marker | NC switch | GPIO3, T21 | Near-end flag, close side.
Override rockers | two paralleled stations | GPIO10 T20, GPIO18 T8 | Edge-trigger open/close. Centre does nothing.
Knob | EC11 | GPIO11–13, on-board | Menu, settings, cancel, acknowledge.

### 7. Needs setup

If origin, marker spans, or the calibration format is invalid, Main blocks automatic motion. Only guided calibration and diagnostic jog may move the motor. Time jog still runs without a trusted shaft position. Position jog needs a healthy encoder but not a known origin (relative counts). Duty and step are edited on those pages. Hall and rocker triggers stay disabled.

The AS5600 is single-turn. The stroke spans several turns. After power loss the firmware enters PositionUnknown and needs a guided seek to the open marker. Direction verify must pass before any limit seek.

With an invalid obstruction table, automatic Main motion stays blocked. Recovery uses the 2.50 A hard ceiling until a relearn arms the table.

Private Reserve · Software User Manual | 9 / 81

Private Reserve · DIN controller · first draft

# Main

Live door state. The spec name is Standard Operating Mode. The operator label is Main. This is the default screen after boot and after wake from a blanked panel.

Draft. Pixel layout: UI/index.html (320 × 170). LCD and web draw the same state tree. The web keypad sits to the right of the panel. Full chrome: overview figure 1 and figure 9 below.

Needs setup blocks automatic motion. Until origin, markers, and an armed obstruction table exist, hall and rocker triggers stay off. The header reads NEEDS SETUP. The hero is a red POSITION UNKNOWN banner. Run Calibration.

### 1. Live screen chrome

Every live Main state uses the same regions. A latched fault replaces the hero and the current meter with a red banner. GPIO numbers, duty, phase timers, bin index, and drift live in Diagnostics, not here.

Region | What it shows
Header left | MAIN when setup is complete, or NEEDS SETUP.
Header right | Link state. Green pip and STA plus the IP, or amber pip and AP plus the SoftAP name (default PrivateReserve). The join password is not in the header.
Hero | Current action in the largest type. A latched fault replaces this with a red banner.
Current | Live amps against the learned trip for the bin the door is in. The red tick is that bin’s trip. The hard 2.50 A ceiling is the right edge. Hidden when a fault banner occupies the hero.
Travel | Share of the measured span in AS5600 counts. Ticks are the two near-end markers. Outer ends are open-seated and closed-seated. The grey line under the bar is percent and counts, or position unknown.
Tiles | Bottle key, open marker, close marker, shaft rev/s. The close-marker title clips to CLOSE MARK… on the 320-pixel panel.
Footer | TURN menu · PRESS menu. Either gesture opens the mode menu.
Private Reserve · Software User Manual | 10 / 81

### 1.1 Needs setup — position unknown

Default after power loss until guided calibration finds origin. Automatic hall and rocker triggers stay off.


Figure 1. Main · needs setup. Position unknown. SoftAP serving.

Private Reserve · Software User Manual | 11 / 81

On screen | Meaning
NEEDS SETUP | Header left. Origin, markers, or the calibration format is invalid. Automatic motion is blocked.
Amber pip + AP PrivateReserve | Header right. Station join failed or SSID is empty. Fallback SoftAP is serving. Default name is PrivateReserve. Default join password is reserved. The header does not show the password. Read it on Settings → Network or Diagnostics → Network. Then open http://192.168.4.1/.
POSITION UNKNOWN | Red banner title. The AS5600 is single-turn. After reset the firmware does not know which turn the door is on.
Automatic motion blocked · run calibration to find origin | Banner detail. Hall and rocker triggers stay disabled until Calibration finds origin.
OPEN / CLOSED | Travel ends. Open is the left of the bar. Closed is the right.
Empty travel track, grey thumb | No fill and no marker ticks in this state. Position is not known, so the bar cannot show a share of span.
position unknown | Left scale under the bar. Replaces percent until origin exists.
— (right of the scale) | Count field. Empty because there is no origin to accumulate from.
BOTTLE KEY · grey pip · ABS · uncal | Hall reads absent. Key levels are not yet captured, so the grey line is uncal instead of an ADC count.
OPEN MARKER · grey pip · CLEAR · travel | Open near-end switch is not made. travel means the door is not at that end (or the end is unknown).
CLOSE MARK… · grey pip · CLEAR · travel | Close near-end switch is not made. Title is Close marker. The tile clips the word.
SHAFT · 0.0 rev/s · — | Motor at rest. Direction dash means no rotation this cycle.
TURN menu · PRESS menu | Either gesture opens the mode menu. Position Unknown is not an acknowledge-away fault.
Private Reserve · Software User Manual | 12 / 81

### 1.2 Opening

Setup is complete. The bottle key went absent. The door is in cruise toward open.

Figure 2. Main · opening. Cruise, key removed.

Private Reserve · Software User Manual | 13 / 81

On screen | Meaning
MAIN | Header left. Setup is complete. Automatic motion is allowed.
Green pip + STA 192.168.1.42 | Header right. ESP32 joined site Wi-Fi as a station. HTTP is on this address.
OPENING (amber) | Hero. Current action. Amber means the motor is moving.
cruise · N in left | Motion phase and remaining throw to the destination marker. The bottle key is absent.
1.42 A | Live motor current from the ACS712 after scale.
Green fill on the current bar | Live amps as a share of the 2.50 A hard ceiling. Green because 1.42 A is under this bin’s trip.
Red tick on the current bar | This bin’s learned trip (1.60 A). Not the hard ceiling.
bin trip 1.60 · max 2.50 | Numeric trip for the bin the door is in, then the compile-time ceiling at the right edge of the bar.
OPEN / CLOSED | Travel ends.
Blue fill to 62%, yellow thumb, two marker ticks | Door is 62% of the measured span toward closed. Marker ticks sit near each end. Neither tick is hot.
62% | Share of measured span. Percent is the headline. Counts sit on the right.
12,690 cnt | AS5600 counts from the open origin.
BOTTLE KEY · grey pip · ABS · adc 1610 | Key absent. Raw ADC is the diagnostic value for this tile.
OPEN MARKER · grey pip · CLEAR · travel | Open switch not made. Door is in mid travel.
CLOSE MARK… · grey pip · CLEAR · travel | Close switch not made.
SHAFT · 1.7 rev/s · CCW | Shaft speed and direction. On this build CCW is toward open.
TURN menu · PRESS menu | Open the mode menu. There is no Stop on Main.
Private Reserve · Software User Manual | 14 / 81

### 1.3 Idle — closed and seated

Move finished. Seal is loaded. Motor is at rest.


Figure 3. Main · idle closed. Seated, snug held.

Private Reserve · Software User Manual | 15 / 81

On screen | Meaning
MAIN | Header left. Setup complete.
Green pip + STA 192.168.1.42 | Station Wi-Fi, HTTP on this IP.
CLOSED | Hero. Door is at the closed-seated end. White, not amber, because the motor is idle.
seated · snug held 0.9 s | How the stop was held. Snug is current-rise seating past the close marker. 0.9 s is hold time this cycle.
0.00 A | Motor current at rest.
Empty current bar, red tick near the right | Live fill is zero. The tick is this bin’s trip (2.20 A).
bin trip 2.20 · max 2.50 | Closed-end bin trip, then the 2.50 A ceiling.
OPEN / CLOSED | Travel ends.
Fill to the closed end, close-marker tick hot | Door is at 100% of span. The close-marker tick is active because the switch is made.
100% · 20,480 cnt | At closed seated. Counts include travel past the close-marker edge.
BOTTLE KEY · green pip · PRES · adc 2980 | Bottle in the recess. Green pip means present on this polarity.
OPEN MARKER · grey pip · CLEAR · travel | Open switch not made.
CLOSE MARK… · green pip · AT END · active | Close switch is made. AT END is the cooked label. active is the raw switch state.
SHAFT · 0.0 rev/s · — | At rest. No rotation this cycle.
TURN menu · PRESS menu | Open the mode menu.
Private Reserve · Software User Manual | 16 / 81

### 1.4 Closing — creep and snug

Past the close marker. The profile has left cruise and is seating the seal.

Figure 4. Main · snug. Past close marker, seating.

On screen | Meaning
MAIN | Header left.
Green pip + STA 192.168.1.42 | Station Wi-Fi.
SNUG (amber) | Hero. Creep-and-seat phase after the close marker. Motor is still moving.
past close marker · seating | Why snug is showing. Operational snug is a current-rise stop, not a home.
1.88 A | Live current. Seal loading raises amps above cruise.
Green fill, red tick near the right | 1.88 A is still under this bin’s 2.24 A trip.
bin trip 2.24 · max 2.50 | Near-closed bin trip, then the hard ceiling.
OPEN / CLOSED | Travel ends.
Fill at 98%, close-marker tick hot | Almost seated. Close switch is made.
98% · 20,070 cnt | Share of span and counts from origin.
BOTTLE KEY · green pip · PRES · adc 2955 | Bottle present. Close was commanded with the key in.
OPEN MARKER · grey pip · CLEAR · travel | Open switch not made.
CLOSE MARK… · green pip · AT END · active | Close switch made.
SHAFT · 0.3 rev/s · CW | Slow creep toward closed. CW is toward closed on this build.
TURN menu · PRESS menu | Open the mode menu. The move ends at seated, a reverse trigger, a fault, or obstruction handling.
Private Reserve · Software User Manual | 17 / 81

### 1.5 Obstruction — reversing

Close current crossed the bin trip. Firmware reversed toward open. Obstruction handling outranks ordinary commands.


Figure 5. Main · reversing. Obstruction while closing.

Private Reserve · Software User Manual | 18 / 81

On screen | Meaning
MAIN | Header left.
Green pip + STA 192.168.1.42 | Station Wi-Fi.
REVERSING (amber) | Hero. Close obstruction. The door is opening to clear the path.
obstruction while closing · opening | Cause and the commanded direction now.
2.11 A | Live current. Above this bin’s trip, so the fill is red.
Red fill past the red tick | Live amps exceeded the learned trip (1.66 A). That is why reverse started.
bin trip 1.66 · max 2.50 | Mid-travel bin trip, then the hard ceiling. Reverse used the learned trip, not the 2.50 A ceiling.
OPEN / CLOSED | Travel ends.
Fill at 48%, neither marker hot | Mid travel. Both switches clear.
48% · 9,830 cnt | Position when reverse is in progress.
BOTTLE KEY · green pip · PRES · adc 2971 | Bottle still present. Close had been the automatic command.
OPEN MARKER · grey pip · CLEAR · travel | Not yet at the open end.
CLOSE MARK… · grey pip · CLEAR · travel | Not at the close end.
SHAFT · 1.4 rev/s · CCW | Opening. CCW toward open on this build.
TURN menu · PRESS menu | Open the mode menu. Reverse still owns the motor until it finishes or faults.
Private Reserve · Software User Manual | 19 / 81

### 1.6 Fault — second close obstruction

A second close obstruction in the retry window latches a fault. The current meter leaves the panel. PRESS acknowledges when firmware allows it.

Figure 6. Main · latched obstruction fault. Press to acknowledge.

On screen | Meaning
MAIN | Header left. Setup is still complete. This is a motion fault, not Needs Setup.
Green pip + STA 192.168.1.42 | Station Wi-Fi.
OBSTRUCTION ×2 | Red banner title. Second close obstruction. The door stopped instead of reversing again.
Repeated close obstruction · press knob to acknowledge | Banner detail. PRESS clears this banner when the firmware allows it. TURN still opens the mode menu.
OPEN / CLOSED | Travel ends. The current meter is hidden while the fault banner occupies the hero.
Red thumb at 44% | Position where the second trip stopped the door. Red track because this is a fault state.
44% · 9,010 cnt | Stopped position.
BOTTLE KEY · green pip · PRES · adc 2969 | Bottle still present.
OPEN MARKER · grey pip · CLEAR · travel | Not at the open end.
CLOSE MARK… · grey pip · CLEAR · travel | Not at the close end.
SHAFT · 0.0 rev/s · — | Motor stopped after the fault.
TURN menu · PRESS menu | On this fault, PRESS acknowledges. TURN opens the mode menu. Position Unknown is the fault that cannot be acknowledged away.
Private Reserve · Software User Manual | 20 / 81

### 2. Mode menu

TURN or PRESS on the live Main screen opens this list. Five items. TURN scrolls. PRESS opens. HOLD returns to the live Main screen.

### 2.1 Five destinations


Figure 7. Mode menu. Five items. Calibration pip is amber because setup is still needed.
Documentation is the fifth row.
On screen | Meaning
MODE | Header left. Same screen family as Main. Not a fourth operating mode.
Green pip + STA 192.168.1.42 | Header right. Same link state as Main.
Blue highlight + left bracket on Main | Selected row. PRESS opens the live Main screen.
Green pip + Main + DOOR | Live door. Value column is the subject of that page.
Green pip + Diagnostics + I/O | Opens the diagnostic menu.
Amber pip + Calibration + NEEDED | Opens the stage list. Amber pip and NEEDED mean origin or later stages are missing. After a full save this row shows green and a status such as armed.
Green pip + Settings + NVS | Opens settings groups. Value is NVS when stored, or unsaved when staged edits exist. If the motor is running, Settings Locked instead.
Green pip + Documentation + GitHub | Opens the Documentation page. QR code for the public project URL.
TURN scroll | Move the highlight.
PRESS open | Enter the highlighted item.
HOLD back | Return to the live Main screen without changing mode.
Private Reserve · Software User Manual | 21 / 81

Web nav tabs send the same jumps: Main, Calibration, Diagnostics, Settings, Docs. They turn the LCD on if it was blank. Settings is a heavier first paint (group list plus a possible NVS write when leaving jog); the firmware feeds the watchdog on that path so HTTP does not die after the list shows.

### 2.2 Documentation

Not an operating mode. A read-only page from the mode menu. Header is DOC. The panel shows a QR code for the public project page and the same path as text. This page does not command the motor. PRESS does nothing. HOLD returns to the mode menu.

Figure 8. DOC. QR and path for the public GitHub page.

On screen | Meaning
DOC | Header left. Documentation page.
Green pip + STA 192.168.1.42 | Header right. Same link state as Main. Amber pip and AP when the fallback SoftAP is serving.
QR code (left) | Encodes https://github.com/KopperToolworks/PrivateReserve. Scan with a phone camera. The enclosure sticker uses the same URL.
github.com/KopperToolworks | Host, as text, if the QR is hard to scan.
PrivateReserve | Repository name.
source and docs | What the page holds. Source, operator docs, and enclosure notes.
scan to open | How to use the QR. On the web copy of this screen, a blue link labelled Open GitHub page opens the same URL. The full web chrome (tabs and keypad) is overview figure 1 and figure 9 below.
HOLD back | Return to the mode menu.
SCAN code | Footer hint. Not a knob gesture. PRESS on this page does nothing.

Pixel source: Main mockup (Documentation state). The enclosure sticker uses the same URL; see DIN/enclosure.md. The repo must stay public or the QR is useless.

Private Reserve · Software User Manual | 22 / 81

### 3. Knob on Main

Gesture | Action
TURN or PRESS (live screen) | Open the mode menu.
PRESS on Documentation | No-op. The QR is the action.
HOLD on Documentation | Return to the mode menu.
PRESS on a latched fault that can be acknowledged | Clear the banner when the firmware allows it. Position Unknown is not an acknowledge-away fault. It needs calibration.
Hall / rocker | Open or close when setup is ready. Edges, not hold-to-run. Open wins if both rocker throws hit in the same cycle.

There is no Stop on this screen. A move ends at destination, snug, a reverse trigger, a fault, or obstruction handling.

### 4. Web page

The LCD shows only the 320 × 170 panel. The phone page adds tabs on top and a keypad on the right. Use landscape. The shell scales to the viewport. There is no application login.

Figure 9. Full web UI on Documentation. Same chrome on every page. Overview figure 1 names every chrome label.

Private Reserve · Software User Manual | 23 / 81

Chrome | Command
Tabs: Main · Calibration · Diagnostics · Settings · Docs | Jump to that page. Active tab is white. They turn the LCD on if it was blank.
Left circular arrow | TURN − (matches CCW on the physical knob)
Right circular arrow | TURN + (matches CW on the physical knob)
Large Return arrow | PRESS
Wide left arrow | HOLD back

On Documentation the web panel also shows Open GitHub page. That link is not on the LCD. PRESS on this page does nothing. HOLD returns to the mode menu.

Private Reserve · Software User Manual | 24 / 81

Private Reserve · DIN controller · first draft

# Calibration

Initial setup and later recals. A full first run does every stage. A later run can open one process. Header prefix is CAL ·.

Draft. Pixel layout: UI/calibration.html. Hardware procedures: Limit_Marker_And_Snug.md, Load_Bin_Obstruction_Calibration.md.

The door will move. Path-clear must pass before any stage that commands the motor. There is no physical E-stop. HOLD cancels: PWM off, wait for current decay, leave K1 unchanged, discard the partial result, return to the stage list. Never write NVS mid-motion. Review is the single save.

Private Reserve · Software User Manual | 25 / 81

### 1. Stage list

Entry for a full setup and for a single recalibration. Status words name stale or missing work so you do not run a later stage on a bad earlier one. Six compact rows fit. TURN windows the list. Door-physics stages come first. The bottle key is last, before Review.

Figure 1. CAL · stages. Stroke entry selected. Stages 7–8 blocked until stroke exists.

Private Reserve · Software User Manual | 26 / 81

On screen | Meaning
CAL · stages | Header left. Calibration mode, stage list.
1–6 of 10 ▾ | Header right. Window into nine capture stages plus Review.
Green pip + 1 · Baselines (current, shaft) + DONE | Stage 1 complete. Two rest captures used by motion: ACS712 zero and AS5600 jitter.
Green pip + 2 · Direction verify + MATCH | Commanded direction agreed with the shaft. Invert flag is good. Gates all seeks.
Green pip + 3 · Open marker → origin + ± 6 CNT | Open-edge probes accepted. Spread across repeats is 6 counts. That edge is count 0.
Green pip + 4 · Close marker → span + ± 9 CNT | Close-edge probes accepted. Spread 9 counts. Edge minus origin is the measured span.
Green pip + 5 · Closed seated + BY CURRENT | Seated found by current rise, not stall. Confirmation, not a home.
Amber pip + highlight + 6 · Stroke entry + NEEDED | Selected row. Operator inches are missing. Required before learn runs, not before marker seeks.
Grey pip + 9 · Obstruction table — empty + BLOCKED | Cannot start until stroke and Door pace exist. Empty-rack learn at the selected pace. Stages 7–8 are spring take-up and Door pace.
Grey pip + 8 · Obstruction table — loaded + OPTIONAL | Second table with racks at max expected load. Skip is allowed.
9 · Bottle door key — 49E | Present and absent levels. After the learn runs so the first pass can stay on door physics.
TURN scroll | Move the highlight. Window the list if more rows exist than fit.
PRESS open | Enter the highlighted stage. Moving stages show path-clear first.
HOLD exit | Return to Main. Incomplete RAM results stay until Review saves or you discard them there.
Private Reserve · Software User Manual | 27 / 81

### 2. Path-clear gate

Shown before any stage that commands the motor. A checklist, not a single OK. The door does not move until every line is ticked.

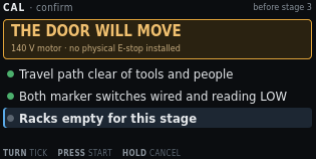
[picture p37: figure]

Figure 2. CAL · confirm, before stage 3. Third line still unticked.

On screen | Meaning
CAL · confirm | Header left. Gate, not a capture screen.
before stage 3 | Header right. This shot is the gate for open-marker seek. Other moving stages show their own number.
THE DOOR WILL MOVE | Amber banner title. Condition before command.
140 V motor · no physical E-stop installed | Banner detail. HOLD is the only cancel. There is no E-stop on this build.
Green pip + Travel path clear of tools and people | Ticked. Operator has acknowledged a clear path.
Green pip + Both marker switches wired and reading LOW | Ticked. NC markers at rest read LOW on this polarity. A HIGH rest would mean a cut wire or a made switch.
Grey pip + highlight + Racks empty for this stage | Not yet ticked. Selected line. TURN moves among lines. This line appears when the stage requires empty racks.
TURN tick | Toggle the highlighted checklist line.
PRESS start | Start the stage when every line is ticked. Does nothing while a line is still grey.
HOLD cancel | Return to the stage list. No motion.
Private Reserve · Software User Manual | 28 / 81

### 3. Stage 1a — current zero

Captured with PWM at zero. ACS712 offset only. It shares nothing with the shaft or key baselines.

Figure 3. CAL · baseline · current. Motor at rest.

On screen | Meaning
CAL · baseline · current | Header left. First of three baseline captures.
1a of 9 | Header right. Stage 1, first sensor, of nine stages.
1.650 V (green) | Hero. Mean ACS712 output at PWM 0. Green means the spread is acceptable.
16 samples at PWM 0 · spread 3 counts | How the mean was taken. Spread is ADC counts, not amps.
raw adc mean · implies · 2 046 / 4095 · 0.00 A | Raw mean of 4095, and the cooked amp reading that offset implies (zero at rest).
scale (fixed) · 185 mV/A · 10k/20k | ACS712-05B sensitivity and the Board A divider. Not an operator edit.
previous capture · 1.648 V · 41 boots ago | Last stored zero, for comparison. No RTC. Age is boot count.
Progress bar, first segment amber, baselines · 1 of 2 | Two motion baselines. This is current zero. Shaft jitter is next.
PRESS accept | Keep this zero in RAM and go to shaft jitter.
HOLD cancel | Discard this capture. Return to the stage list.
Private Reserve · Software User Manual | 29 / 81

### 4. Stage 1b — shaft jitter band

Measured at rest. This band sets stall minimum progress and the accumulation deadband.

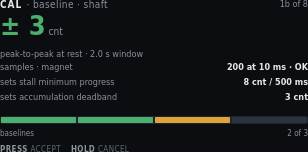
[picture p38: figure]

Figure 4. CAL · baseline · shaft. Rest jitter over 2.0 s.

On screen | Meaning
CAL · baseline · shaft | Header left. Second baseline.
1b of 9 | Header right.
± 3 cnt (green) | Hero. Peak-to-peak AS5600 counts at rest.
peak-to-peak at rest · 2.0 s window | How long the band was watched.
samples · magnet · I2C ACK · detected | Bus then STATUS. I2C ACK means the chip answered. detected / lost / too weak / too strong is magnet quality. I2C NACK plus unread means the bus failed.
sets stall minimum progress · 8 cnt / 500 ms | Stall check needs more motion than rest jitter. Derived from this band, not guessed.
sets accumulation deadband · 3 cnt | Counts inside this band do not walk idle position.
Progress, one green + one amber, baselines · 2 of 2 | Current zero accepted. Shaft is the last motion baseline. The bottle key is stage 9.
PRESS accept · HOLD cancel | Keep the band, or discard and return to the list.
Private Reserve · Software User Manual | 30 / 81

### 5. Stage 2 — direction verify

Runs before any seek. A wrong invert flag would send the first seek at the far end of travel. Slow duty, short move. The operator confirms the door went the way the screen says.

Figure 6. CAL · direction. Match. Invert is unchanged.

On screen | Meaning
CAL · direction | Header left.
2 of 9 | Header right.
MATCH (green) | Hero. Commanded OPEN and the shaft turned the expected way.
commanded OPEN · shaft turned CCW | What firmware asked and what the encoder saw.
+412 cnt | Net counts during the short move.
duty 96 · 1.4 s | Creep duty and how long the probe ran.
invert flag · false (unchanged) | Mapping of K1 to shaft sense. False means the compiled default already matches this cabinet.
current during move · 0.62 A peak | Peak amps on this short move. A stall here is a wiring or bind problem, not a direction problem.
door moved toward · OPEN — confirm on the door | Look at the physical door. The encoder can match a wrong invert if you never look.
Amber line: If the door moved to CLOSE, press to set the invert flag and repeat. | Mismatch path. PRESS sets invert and runs the probe again.
PRESS invert | Flip the invert flag and repeat the short move.
TURN accept | Keep MATCH (or the new invert after a repeat).
HOLD cancel | Discard. Return to the stage list.
Private Reserve · Software User Manual | 31 / 81

### 6. Stage 3 — open marker and origin

Repeat probes of the same edge from the same direction. The spread is the pass criterion. The accepted actuation edge becomes count zero.

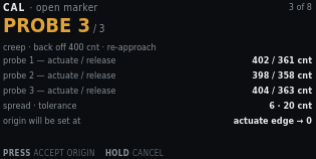
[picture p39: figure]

Figure 7. CAL · open marker. Third probe complete. Spread 6 counts.

On screen | Meaning
CAL · open marker | Header left.
3 of 9 | Header right.
PROBE 3 / 3 (amber) | Hero. Last of three approaches. Amber because the motor just moved.
creep · back off 400 cnt · re-approach | Probe method. Operational snug does not apply during calibration seeks.
probe 1 — actuate / release · 402 / 361 cnt | First pair. Actuation and release differ because the switch has hysteresis. Approach from the same direction each time.
probe 2 — actuate / release · 398 / 358 cnt | Second pair.
probe 3 — actuate / release · 404 / 363 cnt | Third pair.
spread · tolerance · 6 · 20 cnt | Actuate spread across repeats versus the allowed band. 6 is inside 20.
origin will be set at · actuate edge → 0 | Accepted open actuation becomes count zero for everything downstream.
PRESS accept origin | Keep the origin in RAM.
HOLD cancel | Discard a half-probed edge. Partial marker data is not usable.
Private Reserve · Software User Manual | 32 / 81

### 7. Stage 4 — close marker and span

Same probe method at the other end. The accepted edge minus origin is the measured span. Obstruction bins divide this span.

Figure 8. CAL · close marker. Measured span accepted if you press.

On screen | Meaning
CAL · close marker | Header left.
4 of 9 | Header right.
20 180 cnt (green) | Hero. Measured span from origin to close actuation.
measured span · origin to close actuate | What the hero number is. Not seated. Seated is stage 5, past this edge.
probe 1 / 2 / 3 actuate · 20 174 / 20 183 / 20 180 | Three actuation edges. Release edges were captured. This row shows actuate only.
spread · tolerance · 9 · 20 cnt | Spread inside tolerance.
implies shaft revolutions · 4.93 rev | Span divided by 4096 counts/rev. Sanity check against the mechanical stroke.
bin width at 81 bins · 249 cnt | Span divided into 81 obstruction bins.
Progress, three green, close probes · 3 of 3 | All three close probes done.
PRESS accept span · HOLD cancel | Keep the span, or discard the half-probed edge.
Private Reserve · Software User Manual | 33 / 81

### 8. Stage 5 — closed seated

Past the close marker on creep. How the stop was found is stored: a current rise means the seal is loading. A stall without one means the door hit something solid.

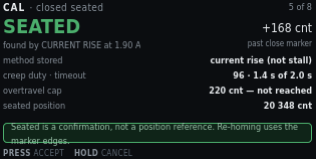
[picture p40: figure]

Figure 9. CAL · closed seated. Found by current rise, 168 counts past the marker.

On screen | Meaning
CAL · closed seated | Header left.
5 of 9 | Header right.
SEATED (green) | Hero. Physical closed stop found.
found by CURRENT RISE at 1.90 A | Method. Prefer current-draw rise (snug). Else record stall.
+168 cnt | Counts past the close-marker actuation.
past close marker | Seated is beyond the near-end flag, not at it.
method stored · current rise (not stall) | Written with the capture so Diagnostics can show why seated was accepted.
creep duty · timeout · 96 · 1.4 s of 2.0 s | Duty used and how much of the seek timeout was consumed.
overtravel cap · 220 cnt — not reached | Hard cap past the marker. A hit here is a fault, not a seated capture.
seated position · 20 348 cnt | Origin-relative counts of the seated stop.
Green line: Seated is a confirmation, not a position reference. Re-homing uses the marker edges. | Do not treat seated as a home. Power-loss recovery seeks the open marker.
PRESS accept · HOLD cancel | Keep seated, or discard.
Private Reserve · Software User Manual | 34 / 81

### 9. Stage 6 — stroke entry

The only operator-typed number, and the only place inches enter the system. It gates learn runs because bin widths are reported in centimetres. It never widens a safety limit.

Figure 10. CAL · stroke. 32.0 in, derived 631 cnt/in.

On screen | Meaning
CAL · stroke | Header left.
6 of 9 | Header right.
Integer inches, then 1/16 | TURN ±1 in, PRESS sixteenths, TURN ±1/16. Fractions reduce (1/2 not 8/16).
inches, open marker → close marker | Tape the two limit switches. Not seated, not cabinet width.
derived 631 cnt/in from 20 348 cnt | Seated counts divided by the typed inches. Display only.
geometric estimate · 640 cnt/in (unverified) | Independent estimate from the mechanical drawing. Unverified means it is not a measured fact.
difference · 1.4% — plausible | Typed stroke versus the geometric estimate. A large disagreement warns. It does not block.
used for · display and warnings only | Inches and counts-per-inch never feed a seek cap.
never used for · seek caps, snug window, bins | Those limits stay in counts from stages 3–5.
Green line: Warns on a large disagreement. It does not block, and it can be re-entered later. | You can fix a typo without repeating marker probes.
TURN adjust | Change the pending inches.
PRESS accept | Keep the stroke in RAM. Unblocks stage 7.
HOLD cancel | Leave the previous stroke (or none).
Private Reserve · Software User Manual | 35 / 81

### 10. Stage 7 — obstruction table, empty racks

Three clear runs each way at the production profile. Obstruction reverse is off. The 2.50 A ceiling stays on. A trip discards that run instead of teaching it.

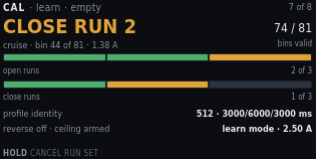
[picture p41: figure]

Figure 11. CAL · learn · empty. Second close run in cruise.

On screen | Meaning
CAL · learn · empty | Header left. Empty-rack table.
7 of 9 | Header right.
CLOSE RUN 2 (amber) | Hero. Second of three close strokes. Motor live.
cruise · bin 44 of 81 · 1.38 A | Profile phase, current bin, live amps.
74 / 81 | Bins that already have a valid sample this run set.
bins valid | Learn runs stop at the marker, so some end bins stay unvisited.
Open-run pips, two green + one amber, open runs · 2 of 3 | Open-direction progress. This shot is mid close-run, so the open bar may already be ahead.
Close-run pips, one green + one amber + one grey, close runs · 1 of 3 | Close-direction progress. Run 2 is live.
profile identity · 512 · 3000/6000/3000 ms | Cruise duty and accel / cruise / decel times. Stored with the table so a later profile change can invalidate it.
reverse off · ceiling armed · learn mode · 2.50 A | Obstruction reverse is off so a bind is not taught as load. The hard ceiling still trips and discards the run.
HOLD cancel run set | PWM off, current decay, K1 unchanged, discard the incomplete table. Return to the stage list. There is no PRESS on this live run.
Private Reserve · Software User Manual | 36 / 81

### 11. Stage 8 — obstruction table, loaded racks

Optional second table with racks at maximum expected load. Which table arms in service is still an open spec decision, so the screen states it.

Figure 12. CAL · learn · loaded. Gate before the loaded run set.

On screen | Meaning
CAL · learn · loaded | Header left.
8 of 9 | Header right.
LOAD THE RACKS | Amber banner title. Do not start this set empty.
Fill to maximum expected capacity before starting this set | Banner detail. Max expected load, not an overload test.
empty table · stored · armed | Stage 7 already produced a usable empty-rack envelope.
loaded table · not yet learned | This stage has not run.
arming rule · undecided — see spec | Which table Main uses in service is not chosen on this panel. See Production_Software.md.
runs required · 3 open · 3 close | Same run count as the empty table.
PRESS start | After racks are loaded, start the run set (path-clear still applies).
HOLD skip | Leave the loaded table unlearned. Review will show it as optional skipped.
Private Reserve · Software User Manual | 37 / 81

### 12. Stage 9 — bottle key levels

Last capture before Review. Two captures: bottle out, then bottle in. Enter and exit thresholds are derived from the gap. The door does not move. Path-clear is not shown.

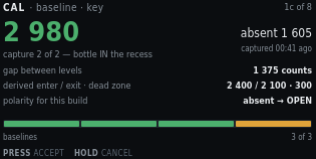
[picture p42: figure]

Figure 5. CAL · bottle key. Second capture, bottle in the recess. Live header is 9 of 9.

On screen | Meaning
CAL · bottle key | Header left. After the learn runs.
9 of 9 | Header right. Last guided capture.
2 980 (green) | Hero. Present-level ADC this capture.
capture 2 of 2 — bottle IN the recess | Operator has placed the bottle. Capture 1 was absent.
absent 1 605 | Right of the hero. First capture, bottle out.
captured 00:41 ago | Age of the absent capture this session.
gap between levels · 1 375 counts | Present minus absent. A small gap means a weak magnet or a bad placement.
derived enter / exit · dead zone · 2 400 / 2 100 · 300 | Hysteresis pair and the dead zone between them. Not a single threshold.
polarity for this build · absent → OPEN | Default handbook polarity. Place the bottle to close. Change it in Settings if this cabinet is wired the other way.
PRESS accept · HOLD cancel | Keep both levels, or discard.
Private Reserve · Software User Manual | 38 / 81

### 13. Review and save

Single NVS write. Everything above lived in RAM until this screen. The blob carries the profile identity that will later invalidate it. Motor must be idle.

Figure 13. CAL · review. One optional stage skipped. Motor idle.

On screen | Meaning
CAL · review | Header left.
save | Header right. This is the write point.
READY TO SAVE (green) | Hero. Completeness check passed.
8 stages complete · 1 optional skipped | Loaded-rack table was skipped. Empty table is enough to leave Needs Setup.
origin · span · seated · 0 · 20 180 · 20 348 cnt | The three count references from stages 3–5.
marker spread (open / close) · 6 / 9 cnt | Probe quality from stages 3 and 4.
stroke → derived · 32.0 in → 631 cnt/in | Typed stroke and the display-only scale.
tables · blob · empty armed · v3 3.6 kB | Which envelope is armed, format version, and blob size.
Green line: Motor is idle and current has decayed. NVS is never written while the motor runs. | If the motor is still spinning, this screen will not write.
PRESS save | One NVS write. Then return toward Main.
HOLD discard | Drop the RAM results. Stored NVS is unchanged.

### 14. Knob on a live stage

Private Reserve · Software User Manual | 39 / 81

Gesture | Typical meaning
TURN | Jog or adjust where the stage allows it (stroke entry, direction accept, checklist tick).
PRESS | Capture, accept, or start the next sample.
HOLD | Cancel the live procedure. Return to the stage list.

When an earlier value changes, mark dependent later steps stale. There is no RTC. Metadata uses run count and relative millis only. Never reverse K1 without PWM blanking.

Private Reserve · Software User Manual | 40 / 81

Private Reserve · DIN controller · first draft

# Diagnostics

One screen per input or output. Focused content is large. Every detail page names the GPIO and Board A terminal and shows the live level. Supporting values stay small. Header prefix is DIAG ·.

Draft. Pixel layout: UI/diagnostics.html. Terminal numbers match Board A.

Both jog pages, run to limit, and the obstruction test own the motor. They carry an amber banner while live. Hall and rocker cannot preempt them. HOLD cancels: PWM off, current decay, K1 unchanged. A short PRESS while moving also drops PWM (sampled in the main loop, not an interrupt). Jog by time queues milliseconds per EC11 detent. While that move is running it does not read the shaft encoder, so a NACK on I²C cannot stretch the queue. Leftover queue time expires on its own. Jog by position queues relative shaft counts. It does not need a known origin. It runs only while the AS5600 ACKs and the magnet is in range; a lost encoder stops PWM. Opening that page polls the encoder. Run to limit starts a jog-duty open or close and stops on the destination marker or PRESS. The shaft encoder is not read while that run is moving. Markers do stop this page. The learned envelope does not.

Private Reserve · Software User Manual | 41 / 81

### 1. Menu

Fourteen items. TURN windows the list. Pips flag anything already unhealthy. PRESS opens. HOLD exits to Main. Figure 1 is an older 12-item shot; live firmware splits jog into time and position and adds run to limit. Items after the first window have their own figures below.

Figure 1. DIAG · menu. First window, bottle key selected. Live list also has Jog by time and Jog by position.

Private Reserve · Software User Manual | 42 / 81

On screen | Meaning
DIAG · menu | Header left.
1–6 of 14 ▾ (live) or the older 1–8 of 12 shot | Header right. Window into the 14-item list. The triangle means more items below.
Green pip + highlight + Bottle door key — 49E + PRESENT | Selected. Hall sensor. Value is live cooked state.
Green pip + Motor rotary encoder — AS5600 + OK | I²C ACK and shaft magnet in range. Amber pip + no mag means the bus is live but STATUS is lost, too weak, or too strong. Red pip + no i2c means the chip did not ACK at 0x36.
Green pip + Limit switches + CLEAR | Neither marker is made.
Green pip + Override rockers + CLOSE HELD | Close throw is made right now. Centre does nothing. PRESS on that page pulses a throw through the same path as the hardware.
Green pip + Motor current load — ACS712 + 0.00 A | Live amps at rest.
Grey pip + Motor PWM and direction + IDLE | Duty zero. Grey pip is idle, not a fault.
Amber pip + Jog by time + no encoder | Amber because this page can command the motor. Timed detents. Shaft encoder is not read.
Amber pip + Jog by position + needs enc or red locked | Count detents. Green magnet required. Locked if I²C or magnet is unhealthy.
Amber pip + Run to limit + no encoder | Amber because this page can command the motor. Full travel at jog duty until the destination marker or PRESS.
Amber pip + Obstruction test + MOVES MOTOR | Same warning. Plastic-bottle test. Does not write the learned table.
TURN scroll · PRESS open · HOLD exit | Window the list, enter the highlighted item, or return to Main.

Full list:

Private Reserve · Software User Manual | 43 / 81

# | Menu item | Value column | Opens

7 | Jog by time | no encoder | Milliseconds per detent. Encoder unused.
8 | Jog by position | needs enc / locked | Counts per detent. Requires a healthy AS5600.
9 | Run to limit | no encoder | Open or close until the destination marker. Encoder unused.
10 | Obstruction test | moves motor | Plastic-bottle envelope test.
11 | Obstruction table | armed / stale | Close-direction graph first. TURN swaps to open.
12 | EC11 knob and button | ok | Quadrature, detent scale, display timeout remaining.
13 | Network and OTA | STA or AP | Address, mDNS, antenna note.
14 | Stored calibration | ok / setup | Which steps are valid and why a stale one failed.

Every detail page keeps a pin strip: GPIO, terminal, function, live level or raw value. HOLD back returns to this menu. Bottle key, limit markers, and override rockers can inject a cooked signal from PRESS. The pin strip stays the real GPIO.

Private Reserve · Software User Manual | 44 / 81

### 2. Bottle door key — 49E

Present and absent are two calibrated levels with separate enter and exit thresholds. Polarity is stated in words because it is configurable. PRESS can pulse the cooked state without moving the bottle.


Figure 2. DIAG · bottle key. Present, last edge 3 min 11 s ago.

Private Reserve · Software User Manual | 45 / 81

On screen | Meaning
DIAG · bottle key | Header left.
1 / 15 | Header right. First of fifteen detail screens. The menu is not numbered here.
PRESENT (green) | Hero. Cooked state after hysteresis. Amber plus SIM when PRESS has forced the state.
pulse · adc 2971 · last edge … | Selected action (pulse or recapture), live ADC, and age of the last cooked edge. Sparkline is the real ADC, newest at the right.
Sparkline + adc · 8 s | Raw ADC, newest at the right (dot). About 8 seconds once the strip is full. The trace scrolls left. The step up is the bottle going in.
absent level (calibrated) · 1 605 | Stage 9 absent capture.
present level (calibrated) · 2 980 | Stage 9 present capture.
enter / exit threshold · 2 400 / 2 100 | Hysteresis pair derived from those levels.
trigger polarity · absent → OPEN | Automatic Main command when the key leaves the recess.
Pin strip: GPIO01 · T23 · ADC1_CH0 · 49E OUT | MCU pin, Board A terminal, ADC channel, sensor output name. Always the real pin, even during a pulse.
2 971 / 4095 · 2.39 V | Live raw and volts at the pin.
TURN action | Pulse the key, or recapture levels. Pulse is the default. The highlight stops at each end. Extra clicks do not wrap.
PRESS pulse | Toggle cooked present/absent. Fires the same open/close edge as the hall sensor. Does not fake the ADC.
PRESS recapture | After TURN: capture absent, then PRESS again with the bottle in. Same two-step as Calibration stage 9.
HOLD back | Return to the diagnostic menu. Clears a simulated key state.
Private Reserve · Software User Manual | 46 / 81

### 3. Motor rotary encoder — AS5600

The only source of door position. It also carries the jitter band and the drift from the last marker resync. I²C health and magnet STATUS are separate: ACK with no mag on the menu means the chip answered and the magnet is unreadable.

Figure 3. DIAG · shaft encoder. 62% of span, magnet OK.

Private Reserve · Software User Manual | 47 / 81

On screen | Meaning
DIAG · shaft encoder | Header left.
2 / 15 | Header right.
12 690 cnt | Hero. Accumulated counts from the open origin.
62% of span · 3.10 rev from origin | Share of measured span, and shaft revolutions since origin.
Angle dial | Single-turn AS5600 angle inside the current revolution. Not the multi-turn door position.
148.3° | That single-turn angle in degrees.
1.7 rev/s CCW | Live shaft speed and direction.
I2C 0x36 · ACK or NACK | Live bus. ACK means the last STATUS/angle read succeeded. Magnet can still be unreadable.
raw angle · magnet · 1 687 · detected | 12-bit raw angle (0–4095) and STATUS: detected, lost, too weak, too strong, or unread if the bus failed.
AGC (mid ~128) · 128 | Automatic gain. Meaningful only on ACK. Mid-range is a healthy air gap.
jitter band at rest · ± 3 cnt | Stage 1b capture. Growing band is an early warning for a weak magnet.
drift last re-sync (open / close) · −12 / +7 cnt | Correction applied the last time each marker was seen. Growing drift means lost turns or a slipping magnet.
Pin strip: GPIO43/44 · T10/T9 · I²C 0x36 · 12-bit | SCL/SDA, terminals, bus address, resolution.
4096 cnt/rev · 100 kHz | Counts per mechanical revolution and I²C clock.
PRESS zero drift log | Clear the displayed per-marker drift totals. Does not change origin.
HOLD back | Return to the menu.
Private Reserve · Software User Manual | 48 / 81

### 4. Limit switches

HIGH is the marker state. A cut wire is indistinguishable from a made switch, so the screen says so. Both markers active is a fault, shown here rather than as a silent refusal to start. PRESS can force a marker without blocking the optical path.


Figure 4. DIAG · limit markers. Both clear, mid travel.

Private Reserve · Software User Manual | 49 / 81

On screen | Meaning
DIAG · limit markers | Header left.
3 / 15 | Header right.
Open marker · GPIO17 · T7 | Left tile title. Pin and Board A terminal.
Grey pip + CLEAR LOW | Open switch not made. Electrical level is LOW.
band 0 – 410 cnt · debounce 3 | Count window where an open-marker actuation is accepted, and debounce samples.
Close marker · GPIO03 · T21 | Right tile title.
Grey pip + CLEAR LOW | Close switch not made.
band 19 770 – 20 180 · deb 3 | Close-marker acceptance window and debounce.
polarity · HIGH = marker or cut wire | NC to GND with pull-up. HIGH means the loop is open: at the end, or the wire is cut.
both active check · pass | Both markers made at once is a fault. Pass means that is not happening.
position now · 12 690 cnt · mid travel | Live counts and a cooked region name.
overtravel cap past marker · 220 cnt | Hard cap after a marker. A seek that passes this is a fault.
Pin strip: NC → GND · INPUT_PULLUP · kLimitActiveLow = false | Wiring and the firmware polarity constant.
17: LOW · 03: LOW | Live GPIO17 and GPIO3 levels. Stays the real pin during a force.
TURN select · PRESS force | Highlight open or close. The highlight stops at each end. Extra clicks do not wrap. PRESS latches that marker as if the switch were made. Amber pip and SIM on the tile. PRESS again clears that force. A forced destination marker will stop a move already in progress.
HOLD back | Return to the menu. Clears a forced marker.
Private Reserve · Software User Manual | 50 / 81

### 5. Override rockers

Two paralleled stations act as one logical switch. Each throw is shown separately. A stuck throw is invisible if you only display the combined result. Both throws at once is a defined tie-break, not a fault. PRESS pulses the selected throw through the same path as the hardware.

Figure 5. DIAG · override rockers. Close throw held.

Private Reserve · Software User Manual | 51 / 81

On screen | Meaning
DIAG · override rockers | Header left.
4 / 15 | Header right.
Open throw · GPIO10 · T20 | Left tile. Open side of both paralleled stations.
Grey pip + OFF HIGH | Open throw not made. Pulled up.
edges 14 · last 00:02:41 | Accepted edges since boot, and age of the last open edge.
Close throw · GPIO18 · T8 | Right tile.
Green pip + MADE LOW | Close throw is held to ground right now.
edges 11 · last 00:00:03 | Close-edge count and the edge three seconds ago.
command model · edge trigger · centre does nothing | Rocker centre is idle. Hold-to-run is not the model.
both throws made · tie-break: OPEN wins | If both throws hit in the same cycle, firmware commands open.
debounce · 25 ms | Switch debounce. Same family as Settings → Triggers.
last accepted command · CLOSE · ignored, already closed | Last edge that passed debounce, and why it did not start a move.
Pin strip: active-low → GND · INPUT_PULLUP · 2 stations | Wiring. Two stations in parallel hide a stuck mate unless this page splits the throws.
10: HIGH · 18: LOW | Live GPIO10 and GPIO18. Stays the real pin during a pulse.
TURN select · PRESS pulse | Highlight open or close. The highlight stops at each end. Extra clicks do not wrap. PRESS injects a short made-edge on that throw, the same command as the physical rocker. It can start a move. Amber pip and SIM while the pulse is live.
HOLD back | Return to the menu. Drops a pulse that has not expired.
Private Reserve · Software User Manual | 52 / 81

### 6. Motor current load — ACS712-05B

Live amps against the learned envelope for the bin the door is in. Trip is a time-plus-threshold decision, so inrush skip and hold time are on the same page.


Figure 6. DIAG · current load. Live 1.42 A in cruise.

On screen | Meaning
DIAG · current load | Header left.
5 / 15 | Header right.
1.42 A | Hero. Cooked motor current.
cruise · bin 38 of 81 | Motion phase and which obstruction bin the door is in.
Sparkline + |I| · 8 s | Absolute current, newest at the right (dot). About 8 seconds once the strip is full. The trace scrolls left. The step up is the start of cruise.
bin envelope mean / peak · 1.23 / 1.38 A | Learned mean and peak for bin 38.
bin trip · hard ceiling · 1.66 A · 2.50 A | This bin’s trip, then the compile-time ceiling.
trip hold · inrush skip · 150 ms · 400 ms | How long current must stay over trip, and how long after PWM-on the envelope is ignored.
zero · scale · 1.650 V · 185 mV/A | Stage 1a zero and the fixed ACS712-05B scale.
Pin strip: GPIO02 · T22 · ADC1_CH1 · 10k/20k divider | Pin, terminal, ADC channel, Board A divider.
2 044 / 4095 · 1.65 V | Live raw and volts. Near the rest zero, plus load.
PRESS recapture zero | Jump to Calibration stage 1a. Motor must be at rest.
HOLD back | Return to the menu.
Private Reserve · Software User Manual | 53 / 81

### 7. Motor PWM and direction

Duty and K1 are separate blocks. Duty must reach zero and current must decay before the relay moves, so the blank timers are on this page.

Figure 7. DIAG · pwm · direction. 50% duty, K1 open.

On screen | Meaning
DIAG · pwm · direction | Header left.
6 / 15 | Header right.
512 / 1023 | Hero. Live duty in 10-bit counts.
50% duty · 15 kHz · 10-bit | Percent, carrier, resolution. Carrier is compile-time. It is not a setting.
K1 OPEN (amber) | Direction relay commanded open. Amber because the coil is energised.
coil energised · settled 4.2 s | K1 has been in this state long enough to be settled.
phase · cruise · N cnt left | Profile phase and remaining counts to the destination marker. Not a cruise-time timer.
blank before / after direction · 100 / 100 ms | PWM-off windows around a K1 change. Never reverse K1 without this blanking.
relay settle · 25 ms | Wait after K1 before PWM may rise.
shaft (supporting) · 1.7 rev/s CCW · 12 690 cnt | Encoder as a supporting signal on this page. The focused page is PWM.
Pin strip: GPIO16 → PWM → 6N137 · GPIO21 → DIR → U4 | PWM path onto Board B, and direction into U4.
16: PWM · 21: HIGH | GPIO16 is toggling. GPIO21 is HIGH for open on this build.
HOLD back | Return to the menu. This page does not command the motor.
Private Reserve · Software User Manual | 54 / 81

### 8. Jog by time

Owns the motor. Each EC11 detent (or web − / +) queues a fixed run time at jog duty. Same-direction clicks add to that queue. Opposite clicks subtract; when the queue is gone, that click reverses through the normal PWM-off, decay, blank, and K1 settle windows. PRESS while idle cycles duty (5–25%) and time per detent (200–1000 ms). While that timed move is running, the shaft encoder is not polled, so I²C NACKs cannot stretch the queue. Idle on this page still reads the AS5600 (same as most diagnostic screens). After PWM stops, one catch-up read refreshes STATUS. Markers and the learned envelope do not start, stop, or abort the move. Current is a live 0–2.50 A graph when the ACS712 is sampling; it is display-only. The pin strip reads encoder ignored.


Figure 8. DIAG · jog by time. Timed queue. Live firmware titles the page MOTOR LIVE — TIME and omits the travel widget.

Private Reserve · Software User Manual | 55 / 81

On screen | Meaning
DIAG · jog by time | Header left.
7 / 15 | Header right.
MOTOR LIVE — TIME | Amber banner. This page owns the motor. Hall and rocker cannot preempt it.
encoder unused — time per detent | Banner detail. AS5600 I²C is skipped only while the timed queue is moving, not while this page is idle.
jog duty · direction · 9 % · CLOSE | Jog PWM as a percent of 10-bit full scale (5–25%). K1 for this jog. PRESS while idle highlights this row; TURN changes it.
step · remaining · 400 ms · 800 ms | Time added per detent (200–1000 ms, 50 ms steps) and how much powered time is still queued. Queue caps at 4 s. Remaining is wall-clock, not loop ticks.
Live amp strip · 0–2.50 scale | ACS712 history. Display-only. Not used to run or stop the jog.
Pin strip: GPIO16 · GPIO21 · encoder ignored | PWM and direction only. No shaft counts on this page.
TURN jog or TURN duty / TURN step | Default: CW queues close, CCW queues open. Same way extends. Opposite shortens, then blanks and reverses.
PRESS stop or PRESS edit / PRESS next | While moving: drop PWM on a short click (after debounce, on release). While idle: cycle Jog → duty % → step ms → Jog.
HOLD exit | Stop if moving, save a pending edit, then return to the menu.
Private Reserve · Software User Manual | 56 / 81

### 9. Jog by position

Owns the motor only while the AS5600 ACKs and STATUS shows a magnet that is neither too weak nor too strong. That is not a trusted origin; calibration is not required. The queue is relative: each detent is shaft counts in the commanded direction from the live unwrap, not distance from open or close. The pin strip may still show accumulated counts from origin when origin is trusted. Opening this page cancels a leftover time-jog move and forces an encoder poll so the lock banner is not a stale STATUS from a skipped I²C window. Each detent uses the same jog duty (default 64 counts, 16–512 in steps of 16). Same-direction clicks extend the count queue (cap 2048). Opposite clicks subtract, then reverse through the same blanking path as time jog. The stall watchdog is armed when PWM starts so an old timer cannot trip on the first frame. Travel-cap (absolute) is not applied on this page. If I²C fails or STATUS drops out of range, PWM stops immediately without latching a sensor fault. While locked, the banner title is ENCODER REQUIRED and the subtitle names the check that failed. No dedicated LCD shot in this set; chrome matches time jog with counts in place of milliseconds.

Private Reserve · Software User Manual | 57 / 81

On screen | Meaning
DIAG · jog by position | Header left.
8 / 15 | Header right.
MOTOR LIVE — COUNTS | Amber banner when I²C ACK and STATUS are good. TURN jogs.
stops if encoder is lost | Banner detail when the sensor is good.
ENCODER REQUIRED | Amber banner. Jog is locked. TURN does not move the motor.
I2C NACK - chip unread at 0x36 | Banner detail. The AS5600 did not ACK. Not a magnet STATUS flag. Bus time is the 10 ms Wire timeout on a failed transfer; too-weak/too-strong do not change that time.
STATUS: magnet too weak | Banner detail. Chip ACKed. STATUS bit “too weak.” Angle was read and discarded.
STATUS: magnet too strong | Banner detail. Chip ACKed. STATUS bit “too strong.”
STATUS: magnet lost | Banner detail. Chip ACKed. Magnet-detect bit clear (and not the too-weak/too-strong pair).
Travel widget | Shown. Live counts and magnet label on the pin strip (AS5600 T5 / T6).
jog duty · direction | Same 5–25% duty as time jog. Shared setting.
step · remaining · counts | Relative counts per detent and remaining in the commanded direction. Not a target absolute position.
TURN jog | Ignored while locked. Otherwise same CW close / CCW open as time jog.
PRESS stop / HOLD exit | Same cancel rules as time jog.
Private Reserve · Software User Manual | 58 / 81

### 10. Run to limit

Owns the motor. TURN selects open (GPIO17 / upper marker) or close (GPIO03 / lower marker). PRESS while idle starts a run at jog duty through the same PWM-off, decay, blank, and K1 settle windows as every other direction change. PRESS while moving drops PWM. HOLD cancels and returns to the menu. The run stops itself when the destination marker is made after debounce. It does not creep, snug, or re-sync origin. Calibration is not required. The shaft encoder is not polled while the run is moving, so an I²C NACK cannot abort it. Idle on this page still reads the AS5600. After PWM stops, one catch-up read refreshes STATUS. Start is refused if that destination marker is already made. Both markers still latch LimitHit. Hard overcurrent and the move timeout still apply. Stall, travel-cap, and the learned envelope do not. Current is a live 0–2.50 A graph when the ACS712 is sampling; it is display-only except for the hard ceiling. The pin strip reads encoder ignored. Duty is the shared jog-duty setting (5–25%), not cruise.

On screen | Meaning
DIAG · run to limit | Header left.
9 / 15 | Header right.
MOTOR LIVE — LIMIT | Amber banner. This page owns the motor. Hall and rocker cannot preempt it.
encoder unused — stop on marker | Banner detail. AS5600 I²C is skipped only while the run is moving. A refused start (already at that marker) replaces this line with the hint.
Open / close tiles | TURN highlights the end to run toward. Live marker state: CLEAR or AT MARK.
jog duty · phase | Shared 5–25% jog PWM and the live blanking or run-to-limit phase.
Live amp strip · 0–2.50 scale | ACS712 history. Display-only except hard overcurrent.
Pin strip: GPIO16 · GPIO21 · encoder ignored | PWM and direction only.
TURN select | Idle only. Ignored while moving so a detent does not abort.
PRESS run / PRESS stop | Idle: start toward the highlighted end. Moving: drop PWM.
HOLD exit | Stop if moving, then return to the menu.
Private Reserve · Software User Manual | 59 / 81

### 11. Obstruction test

Plastic bottle between the doors. Same envelope rules as Main. Does not write the learned table. Learn runs assume a clear path. This test is not a substitute for them.

Figure 9. DIAG · obstruction test. Close trip, reversed, opening.

On screen | Meaning
DIAG · obstruction test | Header left.
10 / 15 | Header right.
TRIPPED — REVERSED | Amber banner title. Close obstruction fired. Reverse is in progress or just finished.
Close obstruction at bin 41 · 2.11 A vs trip 1.65 A | Where and how far over trip.
test load · plastic bottle between doors | Specified test article. Not a body part, not a tool.
expected close / open · reverse once / fault first trip | Close reverses once. Open faults on the first trip. Same as Main.
result this run · reversed, then opened to marker | What this test actually did.
table writes · hard ceiling · disabled · 2.50 A armed | A deliberate obstruction cannot be taught as load. The ceiling stays on.
Pin strip: GPIO02 current · GPIO16 pwm · GPIO21 dir | Signals this test uses.
1.02 A · opening | Live current and direction after reverse.
PRESS run again | Start another close into the bottle.
HOLD exit | Cancel if live, then return to the menu.
Private Reserve · Software User Manual | 60 / 81

### 12. Obstruction table — close direction

Learned envelope as a curve. Breakaway at the open end and seal loading at the close end are the shape you want. A bump in the middle is a bind. The grey block past the close marker is travel the learn runs never enter, because snug is a separate window.


Figure 10. DIAG · table · close. Empty-rack table, live at bin 44.

Private Reserve · Software User Manual | 61 / 81

On screen | Meaning
DIAG · table · close | Header left. Close-direction envelope.
11 / 15 | Header right. Menu item 11 is this pair of graphs.
1A / 2A on the Y axis | Current scale. The window is 0.7–2.6 A so the curve is readable on 170 pixels.
Dashed red line + 2.50 max | Compile-time hard ceiling. Not a learned value.
Blue mean curve | Merged mean current per bin from the learn runs.
Grey band ±σ | One-sigma band around the mean.
Dashed red trip curve | Per-bin trip used on Main.
Thin grey peak curve | Highest sample merged into that bin.
Vertical amber position line | Live door position on this graph.
Dark block near CLOSED | Bins past the close marker. Learn runs never visit them. Snug is a separate window.
Legend: OPEN · mean · ±σ · trip · peak · position · y 0.7–2.6 A · CLOSED | X ends and the plotted series. Y window is stated so the clipped axis is not mistaken for 0–2.50 A.
valid bins · runs merged · 77 of 81 · 3 | Bins with data, and how many strokes were merged.
worst trip · margin to 2.50 A · 2.24 A at bin 0 · 0.26 A | Highest trip on this table (breakaway at the open end) and room left to the ceiling.
Pin strip: GPIO02 live · empty-rack table · 81 bins · 249 cnt | Which table is drawn, bin count, and bin width in counts.
1.21 A · bin 44 | Live current and the bin under the position line.
TURN direction | Swap to the open-direction graph.
PRESS bin detail | Numeric values for the bin under the cursor (not a separate mockup in this set).
HOLD back | Return to the menu.
Private Reserve · Software User Manual | 62 / 81

### 13. Obstruction table — open direction

Same table, other direction. Breakaway is now at the closed end, where the door pulls out of the seal. The unvisited block moves to the open end. Two independent tables are why both views exist.

Figure 11. DIAG · table · open. Breakaway at the closed end.

On screen | Meaning
DIAG · table · open | Header left.
12 / 15 | Header right.
Graph, Y labels, 2.50 max, legend | Same series as the close graph. Shape differs: peak at the closed end.
Dark block near OPEN | Bins before the open marker. Open-direction learn runs never visit them.
valid bins · runs merged · 78 of 81 · 3 | Open-direction bins with data (bins at and after the open marker) and merged run count.
worst trip · margin to 2.50 A · 2.30 A at bin 80 · 0.20 A | Highest open-direction trip (breakaway at the closed end) and room left to the ceiling.
Pin strip: GPIO02 live · empty-rack table · 81 bins · 249 cnt | Same table family as the close view.
1.20 A · bin 44 | Live current and the bin under the position line, read against the open envelope.
TURN direction · PRESS bin detail · HOLD back | Same gestures as the close graph.
Private Reserve · Software User Manual | 63 / 81

### 14. EC11 knob and button

An input with no other home. Detent scale is bench-calibrated, so raw quadrature and the scaled count sit side by side.


Figure 12. DIAG · ec11. Detent scale 100 / 400. Display timeout 5 min.

On screen | Meaning
DIAG · ec11 | Header left.
13 / 15 | Header right.
+37 | Hero. Scaled detents since reset. Sign is CW positive on this shot.
detents since reset · CW | What the hero counts, and last turn sense.
SW released | Knob switch is up.
last press 180 ms | Duration of the last PRESS (under the HOLD threshold).
raw quadrature · 134 counts | Unscaled CLK/DT edges. Compare with the detent hero to check the scale.
detent scale · 100 / 400 | Quadrature-to-detent fraction from ec11_calibration.h (kEc11DetentScaleNumerator / kEc11DetentScaleDenominator). 100/400 is one detent per four edges.
debounce · 25 ms | SW debounce.
display timeout · 5 min · 3:41 remaining | Idle blanking setting and time left until GPIO38 backlight and GPIO15 panel power drop. Default is 5 minutes.
Pin strip: GPIO11 CLK · GPIO12 DT · GPIO13 SW · on-board | EC11 on the T-Display-S3, not a Board A terminal.
1 · 0 · HIGH | Live CLK, DT, SW. SW HIGH is released with pull-up.
PRESS zero count | Reset the detent hero to 0. Does not change calibration constants.
HOLD back | Return to the menu.
Private Reserve · Software User Manual | 64 / 81

### 15. Network and OTA

Setup surface. The steel lid can block the onboard antenna, so that note is on the screen, not only in the build docs. When SoftAP is serving, this page shows the join password in clear (default reserved). The AP name defaults to PrivateReserve. After join, open http://192.168.4.1/. PRESS rejoin retries the stored STA SSID. To drop that SSID, use Settings → Service → Clear station Wi-Fi, then reboot.

Figure 13. DIAG · network. STA joined, OTA idle-only.

On screen | Meaning
DIAG · network | Header left.
14 / 15 | Header right.
192.168.1.42 (green) | Hero. Station address when STA joined.
STA · house-iot · −63 dBm | Role, stored SSID, RSSI.
mDNS · private-reserve.local | mDNS name for HTTP on the joined LAN.
fallback AP · web clients · PrivateReserve idle · 1 | SoftAP name, idle because STA joined, and one HTTP client. If SoftAP is the live link, this row is join password and the WPA2 PSK (default reserved) instead.
OTA · idle only · armed | OTA is allowed only while the motor is idle. Armed means the endpoint is listening.
antenna · onboard · lid must be open | No external SMA. Close the steel lid and RSSI can collapse.
Pin strip: onboard radio · no external SMA · 0 Ω jumper not moved | Antenna path as shipped. Do not move the 0 Ω jumper unless you fit an external antenna.
STA joined | Live radio role.
PRESS rejoin | Retry STA join with the stored SSID. If join fails, SoftAP starts. This does not clear the stored password. To wipe station credentials, use Settings → Service → Clear station Wi-Fi, then reboot from that result screen or from Reboot controller.
HOLD back | Return to the menu.
Private Reserve · Software User Manual | 65 / 81

### 16. Stored calibration

Answers whether this controller may run automatically, and why not. Stale entries name the value that invalidated them.

Figure 14. DIAG · calibration. Loaded table stale after cruise duty 512 → 544.

On screen | Meaning
DIAG · calibration | Header left.
15 / 15 | Header right. Last detail screen.
Green pip + Direction · origin · span + OK | Stages 2–4 stored and valid.
Green pip + Marker edges (both) + ± 6 CNT | Open/close probe spread still inside tolerance. The value column shows the open-side figure on this shot.
Green pip + Closed seated · by current + OK | Stage 5 method still current-rise.
Green pip + Stroke 32.0 in → 631 cnt/in + OK | Stage 6 still matches the stored span.
Green pip + Obstruction table — empty racks + ARMED | Empty envelope is in service.
Amber pip + highlight + Obstruction table — loaded racks + STALE | Selected. Loaded table is not usable.
Grey pip + stale since cruise duty 512 → 544 | Why. A motion-profile change invalidates both tables. This row names the field that did it.
Pin strip: NVS · format v3 · written 41 boots ago | Where the blob lives, format, age in boots (no RTC).
3.6 kB blob | Stored size.
PRESS open | Jump to the matching Calibration stage for the highlighted row.
HOLD back | Return to the menu.
Private Reserve · Software User Manual | 66 / 81

Private Reserve · DIN controller · first draft

# Settings

Not a fourth operating mode. A menu reached from Main, the same way as Calibration and Diagnostics. Header prefix is SET ·. Motion is idle while values are edited. Service holds the destructive actions: erase tables, restore defaults, clear calibration, clear station Wi-Fi, and reboot the controller.

Draft. Pixel layout: UI/settings.html. NVS names and defaults: T-Display-S3_Firmware_Config.md.

Never write NVS while the motor runs. If you open Settings during a move, the panel shows SETTINGS LOCKED. Pending edits stay in RAM. Retry when idle. A profile or travel change that invalidates learned tables says so on its own screen and again on confirm.

Private Reserve · Software User Manual | 67 / 81

### 1. Groups

Grouped by effect, not by NVS layout. The count on the right is how many values sit in each group. An amber pip marks a group that holds an unsaved change. Six rows fit. Service is the seventh row, off this shot until you TURN.

The web Settings tab paints that group list from /api/state, then keeps polling. Leaving jog to open Settings can write NVS on the same HTTP request as the first paint. The 3 s task watchdog used to miss those stretches, so the list appeared once and the controller stopped answering. Firmware now resets the watchdog around NVS, HTTP, and LCD draw, and it will not walk an unterminated NVS string forever.

Figure 1. SET · groups. Three unsaved changes. Motion profile selected.

Private Reserve · Software User Manual | 68 / 81

On screen | Meaning
SET · groups | Header left. Settings root.
3 unsaved ▾ | Header right. Three staged field edits. The triangle means more groups below.
Amber pip + highlight + Motion profile + 4 VALUES | Selected. Door pace, min duty, creep, jog. Amber when pace is staged (invalidates tables).
Green pip + Travel and markers + 6 VALUES | Caps, probe tolerance, resync drift. Some rows open a locked derived page.
Amber pip + Obstruction detection + 5 VALUES | Inrush skip, snug amps, envelope knobs. Amber because this group also holds a staged edit in this example.
Green pip + Triggers and debounce + 3 VALUES | Bottle-key polarity and switch debounce. Saving polarity re-arms from the current sensor level. It does not command a move.
Green pip + Display and knob + 3 VALUES | Display timeout (minutes, default 5), HOLD min ms, HOLD max ms.
Green pip + Network + 5 VALUES | STA SSID, STA password, join timeout, AP name, AP password. Station password is web-only. Fallback AP password is shown in clear (default reserved). This row is clipped at the bottom of the panel. A 4-byte NVS layout shift used to advertise SoftAP as ateReserve (the tail of PrivateReserve). Boot now restores the default name and password when that suffix is all that remains, then rewrites NVS.
Service and defaults + 5 ACTIONS (off-screen) | Seventh group. TURN to it. Destructive. Figure 11. Clear station Wi-Fi is the fourth action; Reboot controller is the fifth. PRESS twice.
TURN scroll | Move the highlight. Window the list.
PRESS open | Enter the highlighted group.
HOLD exit | Return to Main. Staged edits stay in RAM until Review saves or discards them.
Private Reserve · Software User Manual | 69 / 81

### 2. Motion profile group

A value list, not a form. Pending edits show the new value in amber next to the stored one. Decelerate is the seventh row, off this shot.

Figure 2. SET · motion. Cruise duty staged 512 → 544.

On screen | Meaning
SET · motion | Header left.
7 values | Header right. Count in this group.
Highlight + Door pace | Selected. Gentle…Brisk slider, speed-vs-throw graph, About X s and peak g. Changing pace invalidates both learned tables.
Minimum moving duty · 64 | Floor while the profile is moving. Below this the motor may not break away.
Creep duty · 96 | Duty for marker seeks, snug, and short calibration moves.
Jog duty · 96 | 10-bit duty for both diagnostic jog pages. Those pages edit it as 5–25%. Time jog also edits step as 200–1000 ms. Position jog edits step as 16–512 counts.
Accelerate · 3000 MS | Time to climb from moving floor to cruise. Changing it invalidates tables.
Cruise time · 6000 MS | Time at cruise duty. Changing it invalidates tables. Clipped at the bottom of this shot.
Decelerate · 3000 MS (off-screen) | Seventh value. TURN to it. Time to drop from cruise to creep. Changing it invalidates tables.
TURN scroll · PRESS edit · HOLD back | Move, open the edit screen, or return to groups.
Private Reserve · Software User Manual | 70 / 81

### 3. Edit — cruise duty

The sharpest setting on the controller. Range, default, and step are on the panel. The consequence line is stated before the edit is accepted.

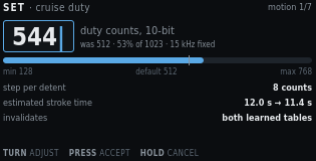
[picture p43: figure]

Figure 3. SET · cruise duty. Pending 544. Invalidates both tables.

On screen | Meaning
SET · cruise duty | Header left. Field name.
motion 1/7 | Header right. First field in the motion group.
544 with caret, blue box | Pending value. TURN changes it.
duty counts, 10-bit | Unit. Same 0–1023 scale as the PWM diagnostic.
was 512 · 53% of 1023 · 15 kHz fixed | Stored value, percent of full scale, and the compile-time carrier. 15 kHz is not editable.
Blue fill on the range bar, white tick | Fill is the pending value. The tick is the default (512).
min 128 · default 512 · max 768 | Allowed range and factory default. Max is below 1023 so cruise cannot sit on the rail.
step per detent · 8 counts | How much TURN changes the pending value.
estimated stroke time · 12.0 s → 11.4 s | Advisory. Faster cruise shortens the move. Not a safety limit.
invalidates · both learned tables (amber) | Accepting this drop both envelopes to stale. Until a relearn, trip is the 2.50 A ceiling only.
TURN adjust · PRESS accept · HOLD cancel | Change, keep the pending value (then confirm), or restore 512.
Private Reserve · Software User Manual | 71 / 81

### 4. Confirm — consequence of the edit

Shown when an accepted edit invalidates learned data. Dropping to the hard ceiling is a real reduction in protection, so it is spelled out and needs a second press.

Figure 4. SET · confirm. Cruise duty will stale both obstruction tables.

On screen | Meaning
SET · confirm | Header left.
cruise duty | Header right. Which field triggered this gate.
RELEARN REQUIRED | Amber banner title.
Changing the profile invalidates both obstruction tables | Banner detail. Door pace does this (same as the old cruise/accel/decel knobs).
Amber pip + Empty-rack table + ARMED → STALE | Empty envelope is in service now. After this save it will not be.
Amber pip + Loaded-rack table + STALE → STALE | Already stale. Stays stale.
Red pip + Until relearn, trip is + 2.50 A CEILING ONLY | Protection drops to the hard ceiling. Main still runs, with less discrimination.
PRESS accept change | Keep the pending cruise duty. Tables mark stale on Review save, not on this press alone.
HOLD keep 512 | Drop the pending edit. Stored 512 stays.
Private Reserve · Software User Manual | 72 / 81

### 5. Edit — display timeout

A benign value, shown for contrast. No consequence line, no confirm step. Units are minutes because that is how an operator thinks about a screen going dark.

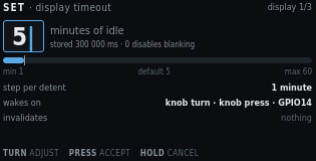
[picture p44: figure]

Figure 5. SET · display timeout. Default 5 minutes. Invalidates nothing.

On screen | Meaning
SET · display timeout | Header left.
display 1/3 | Header right. First of three Display and knob fields.
5 with caret | Pending minutes of idle before blanking.
minutes of idle | Unit on the panel. Firmware stores milliseconds.
stored 300 000 ms · 0 disables blanking | NVS value for 5 minutes. Zero means the panel stays on.
Range bar, min 1 · default 5 · max 60 | Allowed minutes. Default matches the factory 300000 ms.
step per detent · 1 minute | TURN step.
wakes on · knob turn · knob press · GPIO14 | What resets the timer and what wakes a blanked panel. Web commands also reset it. Wake returns to Main.
invalidates · nothing | This field does not stale calibration or tables. Dim on purpose.
TURN adjust · PRESS accept · HOLD cancel | Same edit gestures as cruise duty. No confirm step after PRESS.
Private Reserve · Software User Manual | 73 / 81

### 6. Edit — trigger polarity

An enumerated choice, so it is a two-item pick list rather than a number. Saving re-arms the trigger from the level the sensor is reading now, which is why that line is on the screen.

Figure 6. SET · key polarity. Default: absent opens. Key reads PRESENT now.

On screen | Meaning
SET · key polarity | Header left.
triggers 1/3 | Header right. First of three Triggers and debounce fields.
Green pip + highlight + Bottle absent opens the door + DEFAULT | Selected choice. Handbook polarity. Place the bottle to close.
Grey pip + Bottle present opens the door | Inverted polarity. Use only if this cabinet is wired that way.
key reads now · PRESENT · adc 2 971 | Live cooked state and raw ADC, so you can see what re-arm will start from.
on save · re-arm from current level, no move | Firmware adopts the new polarity from the present reading. It does not command open or close.
client handbook says · place the bottle to open (amber) | Published client instruction. Compare it with the selected row before you accept. Absent-opens means remove the bottle to open. Present-opens means place the bottle to open.
TURN choose · PRESS accept · HOLD cancel | Move the highlight, stage the choice, or keep the previous polarity.
Private Reserve · Software User Manual | 74 / 81

### 7. Network group

Text entry through one knob is a trap, so the LCD shows the values and points at the web page. The station password is masked. The fallback AP password is shown in clear (default reserved) so a phone can join PrivateReserve before /wifi exists. Then open http://192.168.4.1/. The web View of this screen adds a clickable Set SSID and password link, the same idea as Docs adding Open GitHub page. That form is hosted by the controller at /wifi and is not drawn on the LCD. Scan takes a few seconds. The page stays live. The screen states that the web interface has no login. To drop the stored STA network, do not edit this list: use Service → Clear station Wi-Fi, then reboot.

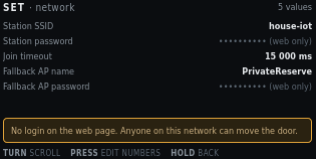
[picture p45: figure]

Figure 7. SET · network. Station password masked. Fallback AP password in clear. No application login.

Private Reserve · Software User Manual | 75 / 81

On screen | Meaning
SET · network | Header left.
5 values | Header right.
Station SSID · house-iot | Stored STA network name. Shown in clear.
Station password · ******** (web only) | Masked. The LCD cannot edit it. On the web View of this screen, open Set SSID and password. That is a separate page at /wifi on the controller, with a phone keyboard and a Scan list. Scan takes a few seconds; the page stays live. It is not on the LCD.
Join timeout · 15 000 ms | How long STA join may run before SoftAP starts. This is a number. PRESS can edit it from the knob.
Fallback AP name · PrivateReserve | SoftAP SSID when STA is empty or join fails. Default name is PrivateReserve. If NVS was shifted by four bytes, this used to load as ateReserve; boot restores the default and rewrites the blob.
Fallback AP password · reserved | Shown in clear. You need this before the web page exists. Default is reserved. Empty means an open AP. Change it later on /wifi.
Amber line: No login on the web page. Anyone on this network can move the door. | HTTP is port 80 with no application login. Do not expose that LAN.
TURN scroll | Move among rows.
PRESS edit numbers | Edit join timeout (and other numeric fields). SSID and passwords do not open a knob editor. On the web, a blue Set SSID and password link opens /wifi. To drop the stored STA network, use Service → Clear station Wi-Fi.
HOLD back | Return to groups.
Private Reserve · Software User Manual | 76 / 81

### 8. Derived and locked values

Read-only by design. Counts-per-inch came from a measured span and a typed stroke. The ceiling and the PWM carrier are hardware facts. Showing them with a lock stops somebody hunting for an edit screen.

Figure 8. SET · derived · locked. Recalibrate to change these.

On screen | Meaning
SET · derived · locked | Header left.
read only | Header right. No edit affordance.
Measured span · 20 180 cnt · from stage 4 | Close-marker actuation minus origin. Dim because it is not editable here.
Counts per inch · 631 · derived from stroke | Display scale only. Never a seek cap.
Seated position · 20 348 cnt · stage 5 | Closed seated counts.
Hard current ceiling · 2.50 A · compile-time | Not an NVS setting. Firmware constant.
PWM carrier · 15 kHz · 10-bit | Not an NVS setting. Hardware/firmware fact.
Green line: Recalibrate to change these. No settings screen can adjust them. | Span and seated change only through Calibration. Ceiling and carrier do not change in the field.
HOLD back | Return. There is no PRESS.
Private Reserve · Software User Manual | 77 / 81

### 9. Review and save pending changes

The single write point, mirroring Calibration review. It lists every staged change with old and new value. It will not write while the motor is running.

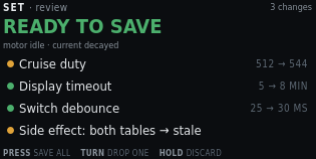
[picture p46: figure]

Figure 9. SET · review. Three field edits plus the table-stale side effect.

On screen | Meaning
SET · review | Header left.
3 changes | Header right. Three field writes in this set. The side-effect row is extra.
READY TO SAVE (green) | Hero. Motor idle, current decayed.
motor idle · current decayed | Write precondition. Same rule as Calibration review.
Amber pip + Cruise duty + 512 → 544 | First staged write. Amber because it invalidates tables.
Green pip + Display timeout + 5 → 8 MIN | Second staged write. Benign.
Green pip + Switch debounce + 25 → 30 MS | Third staged write.
Amber pip + Side effect: both tables → stale | Not a field you typed. Consequence of cruise duty. Named so it cannot be missed.
PRESS save all | One NVS write of the remaining rows.
TURN drop one | Remove the highlighted row from this set. It stays at the stored value.
HOLD discard | Drop the whole set. Stored NVS is unchanged.
Private Reserve · Software User Manual | 78 / 81

### 10. Edit blocked — motor busy

A defined refusal, not an error. Configuration cannot change under a running profile or an active calibration stage. The screen names which one is holding the lock.

Figure 10. SET · blocked. Door closing. Three pending edits kept in RAM.

On screen | Meaning
SET · blocked | Header left.
no write | Header right. This screen will not commit NVS.
SETTINGS LOCKED | Red banner title.
Door is closing · configuration writes need an idle motor | Banner detail. Why, and the rule.
holder · automatic close · cruise | Which activity owns the motor. Could also name a calibration or jog step.
pending changes · 3 kept in memory | Staged edits survive. They are not discarded by the lock.
retry · when motion completes or faults | Open Settings again after idle. Review can then save.
HOLD back | Leave. No PRESS. There is nothing to accept.
Private Reserve · Software User Manual | 79 / 81

### 11. Service and defaults

Destructive actions live together, away from ordinary edits. Each states its blast radius. PRESS confirm twice. Motor must be idle. Full factory erase is USB-only. It is not on this menu.


Figure 11. SET · service. Five actions. Erase tables selected. Confirm twice. Clear station Wi-Fi and Reboot controller are the fourth and fifth rows.

On screen | Meaning
SET · service | Header left.
5 actions | Header right. Not values. Actions.
Red pip + highlight + Erase obstruction tables + BOTH | Selected. Drops empty and loaded envelopes. Origin stays. Hard ceiling until relearn.
Amber pip + Restore setting defaults + KEEPS CALIBRATION | Settings struct reset. Keeps calibration. Keeps Wi-Fi strings.
Red pip + Clear calibration and origin + FORCES SETUP | Main shows Needs Setup. Automatic motion blocks until Calibration runs again.
Amber pip + Clear station Wi-Fi + SOFTAP AFTER REBOOT | Zeros stored STA SSID and password. Fallback AP name and password stay. The live STA session stays until reboot. Next boot skips STA and starts SoftAP.
Amber pip + Reboot controller + NOW | Stops PWM and resets the ESP32. Same as a power cycle. Motion does not resume. PRESS twice, motor idle.
selected action · erases both envelopes · hard ceiling until relearn | Blast radius of the highlighted row, restated under the list.
PRESS confirm twice | First PRESS arms. Second PRESS runs. HOLD at either step aborts. TURN after the first PRESS cancels the arm.
HOLD back | Return to groups without running an action.
Private Reserve · Software User Manual | 80 / 81

### 12. Station Wi-Fi cleared

Shown after Clear station Wi-Fi runs. The write is already in NVS. PRESS reboots now so SoftAP can start. HOLD returns to Settings if you want to reboot later from Service.

Figure 12. SET · wifi. Station SSID empty. PRESS reboots. HOLD leaves this session on the old STA address.

On screen | Meaning
SET · wifi | Header left.
reboot | Header right. The change is stored. SoftAP starts on the next boot.
WIFI CLEARED | Warn banner. Station SSID and password are empty.
PRESS reboot · SoftAP on next boot | This session can stay on the old STA address until you PRESS or power-cycle.
Station SSID · (empty - AP only) | Boot will skip STA join.
Fallback AP name · PrivateReserve | Unchanged. Join this AP after reboot, then set a new SSID on the web.
Join password · reserved | WPA2 PSK for that AP. Type it on the phone. Shown here because the web page is not reachable until you join.
After reboot · join AP, then set SSID on the web | SoftAP starts. Then open http://192.168.4.1/wifi. The live STA link, if any, stays until this reboot.
PRESS reboot | Stops PWM and resets the ESP32. One PRESS. Motor must be idle.
HOLD back | Return to Settings groups without rebooting.
Private Reserve · Software User Manual | 81 / 81

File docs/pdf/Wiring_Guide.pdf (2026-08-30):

Private Reserve · DIN controller

# Wiring Guide

Boards A, B, and C as built: earth-side control, floating gate driver, and HV switch stage.

Screw-terminal IDs on these pages are the names used on the operator screens.

### 1. Board A — Earth-side control 2. Board B — Floating gate driver 3. Board C — HV switch stage

Private Reserve · Wiring Guide | 1 / 19

Private Reserve · DIN controller · first draft

## Board A — Earth-side control

Dual Adafruit Perma-Proto 1/2 carrier for the LilyGo T-Display-S3 and the EC11 menu encoder. Field I/O and power leave through edge screw terminals. This board is earth-referenced only.

Draft. Header pin order along each edge is taken from the carrier with the display up and USB-C
on the left. The LilyGo pinmap photo is the module bottom, so its LEFT/RIGHT labels are mirrored here. Screw terminals are numbered T1–T24 left to right on each edge (T1 nearest USB). Outer rails are as-built. Inner rails are proposed. Column span 7–18 is assumed. On-board jumper paths are documented elsewhere.

No floating copper. Do not land +5V_ISO, +12V_GD, −70V, +70V, or SW on Board A. MCU_GND is not
−70V.

### 1. Placement

View with the display facing you. USB-C is on the left. The EC11 is on the right. Pin 12 of each header is nearest USB. Screw terminals are numbered T1–T12 on the top edge and T13–T24 on the bottom edge, left to right. The top edge starts at T1 (3V, GND, one NC, then PWM, DIR, limits, I²C). The bottom edge starts at T13 (5V, GND, five NC including T17–T19, then OPEN, LIM-L, ISENSE, HALL, 3V). The EC11 uses GPIO11–13 on the T-Display header directly; see EC11 on-board wiring.

Private Reserve · Wiring Guide | 2 / 19

Board A — placement (first draft)
USB-C left · EC11 right · header pin 12 nearest USB · outer rails as-built · inner rails proposed
TOP edge · left → right

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
LIM-U

T8
CLOSE

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
unused
unused
1 | 5 10 | 15 | 20 | 25 | 30
| | Adafruit Perma-Proto 1/2

+3.3V
GND

upper

USB | T-Display-S3 | LILYGO

3V GND GND NC PWM DIR LIM-UCLOSE SCL SDA GND GND

5V GND NC NC | 13 | 12 | 11 OPEN LIM-LISENSEHALL 3V

EC11
CLK · DT
SW
+ · GND

GND
+3.3V
1 | 5 10 | 15 | 20 | 25 | 30
| | Adafruit Perma-Proto 1/2

unused
GND

lower

BOTTOM edge · left → right

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
OPEN

T21
LIM-L

T22
ISENSE

T23
HALL

T24
3V
Rail and pin colors
+5V (earth) +5V_EARTH | +3.3V (earth) +3V3_TDISPLAY | GND (earth) MCU_GND
Field GPIO / command | EC11 header pins (on-board, not terminals) | NC terminal / unused rail

Draft. Upper outer rails unused. Lower outer + unused; lower outer − is MCU_GND.
+5V_EARTH is the 5V screw terminal, not a proto + bus. Column span 7–18 is assumed.

Figure 1. Grid-true placement. Terminal IDs T1–T24 label each screw block left to right. Dashed gray bars are unused rails (as-built: both upper outer buses, and the lower outer +). Purple dots are T-Display header pins wired to the on-board EC11 (GPIO11–13). T17–T19 are NC; the encoder does not use those terminals.

### 2. Rails

Each half has four full-width buses. On the as-built unit both upper outer rails are unused, and the lower outer + rail is unused. The lower outer − rail is MCU_GND. Inner-rail nets below are still proposed. +5V_EARTH lands on the 5V screw terminal and the T-Display 5V pin; it is not on a proto + bus. Sensors / EC11 + should see +3V3_TDISPLAY from the module 3V pin. Do not back-feed 3.3 V into the module.

Private Reserve · Wiring Guide | 3 / 19

Rail | Net | Diagram color
Upper outer − | unused (as-built; no jumper) | unused
Upper outer + | unused (as-built; no jumper) | unused
Upper inner + | +3V3_TDISPLAY (proposed) | +3.3V (earth)
Upper inner − | MCU_GND (proposed) | GND (earth)
Lower inner − | MCU_GND (proposed) | GND (earth)
Lower inner + | +3V3_TDISPLAY (proposed) | +3.3V (earth)
Lower outer + | unused (as-built; no jumper) | unused
Lower outer − | MCU_GND (as-built) | GND (earth)

### 3. What attaches

Power

Board A runs from the earth-side Mean Well HDR-15-5 #1 supply (+5V_EARTH / MCU_GND). Land the PSU positive on T13 (5V) and the PSU negative on T14 (GND). Those terminals feed the T-Display 5V pin and the board MCU_GND reference. USB-C on the module remains for bench programming. Do not back-feed 3.3 V into the module 3V pin.

Screw terminals

Numbering follows Figure 1: left to right with the display facing you and USB-C on the left. T1 and T13 are nearest USB.

Top edge — T1–T12

Private Reserve · Wiring Guide | 4 / 19

Terminal | Label | GPIO / net | Attaches
T1 | 3V | +3V3_TDISPLAY | SS49E VCC, AS5600 VCC (from module 3V)
T2 | GND | MCU_GND | Sensor, limit, and rocker returns
T3 | GND | MCU_GND | Sensor, limit, and rocker returns. Lands R6 (PWM) and R7 (DIR) 10 kΩ pull-downs
T4 | NC | — | Module NC. Unassigned. May be jumpered to MCU_GND.
T5 | PWM | GPIO16 | Board B 6N137 LED. On-board R6 10 kΩ to T3 MCU_GND
T6 | DIR | GPIO21 | Board B U4 LED. On-board R7 10 kΩ to T3 MCU_GND
T7 | LIM-U | GPIO17 | Upper NC limit to GND
T8 | CLOSE | GPIO18 | Close rocker (active-low, paralleled pair)
T9 | SCL | GPIO44 | AS5600 SCL
T10 | SDA | GPIO43 | AS5600 SDA
T11 | GND | MCU_GND | Sensor, limit, and rocker returns; Board B LED return
T12 | GND | MCU_GND | Sensor, limit, and rocker returns

Bottom edge — T13–T24

Private Reserve · Wiring Guide | 5 / 19

Terminal | Label | GPIO / net | Attaches
T13 | 5V | +5V_EARTH | Power in. Mean Well HDR-15-5 #1 (+) → T-Display 5V
T14 | GND | MCU_GND | Power in. Mean Well HDR-15-5 #1 (−) / earth-side return
T15 | NC | — | Module NC. Unassigned.
T16 | NC | — | Module NC. Unassigned.
T17 | NC | — | Unassigned. Same index as GPIO13; EC11 SW is on-board from the header (EC11 wiring).
T18 | NC | — | Unassigned. Same index as GPIO12; EC11 DT is on-board from the header.
T19 | NC | — | Unassigned. Same index as GPIO11; EC11 CLK is on-board from the header.
T20 | OPEN | GPIO10 | Open rocker (active-low, paralleled pair)
T21 | LIM-L | GPIO3 | Lower NC limit to GND
T22 | ISENSE | GPIO2 | ACS712-05B OUT after 10 kΩ/20 kΩ (≤ 3.3 V)
T23 | HALL | GPIO1 | SS49E OUT
T24 | 3V | +3V3_TDISPLAY | SS49E VCC, AS5600 VCC (from module 3V)

EC11 (on-board)

The menu encoder wires directly to T-Display-S3 header pins. It does not use screw terminals. Terminals T17–T19 are NC on the as-built unit.

EC11 breakout | T-Display pin | GPIO / net
CLK | LEFT GPIO11 | GPIO11
DT | LEFT GPIO12 | GPIO12
SW | LEFT GPIO13 | GPIO13
+ | 3V | +3V3_TDISPLAY
GND | GND | MCU_GND

Full notes, terminal clarification, and links: EC11 on-board wiring.

On-board pull-downs

R6 (10 kΩ) sits between T5 (PWM, GPIO16) and T3 (MCU_GND). R7 (10 kΩ) sits between T6 (DIR, GPIO21) and the same T3 return. They hold the Board B optocoupler LEDs off if the T-Display is unpowered or resetting. Series LED resistors stay on Board B.

Private Reserve · Wiring Guide | 6 / 19

Board A → Board B

Keyed 3-pin earth-side cable from T5 (PWM), T6 (DIR), and a MCU_GND terminal (for example T11 or T14). LED resistors stay on Board B.

### 4. As-built photo

Line art is the labeled figure. The photo shows the unit that was built.

Private Reserve · Wiring Guide | 7 / 19

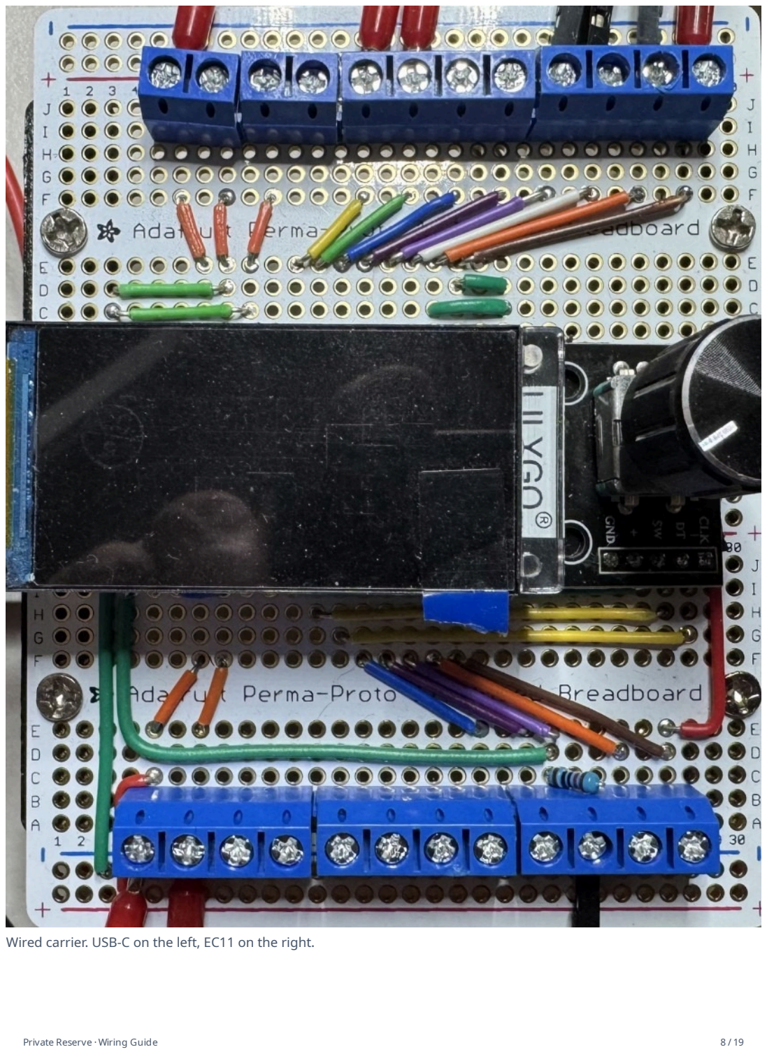
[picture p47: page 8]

Wired carrier. USB-C on the left, EC11 on the right.

Private Reserve · Wiring Guide | 8 / 19

Private Reserve · DIN controller · first draft

## Board B — Floating gate driver

Single Adafruit Perma-Proto 1/2 carrier for the 6N137 / 4N35 optocouplers, Q2 fail-off, TC4426 gate driver, and Q3 K1 coil switch. Earth-side LED inputs occupy columns 1–5; the floating gate-driver region occupies columns 6–30. Floating power and inter-board links leave through screw terminals on the board edges.

Draft. View with U1 (6N137) on the left and U4 (4N35) on the right, matching the as-built photo. Vertical stacks (T1–T3 upper left, T6–T7 lower left) are numbered top → bottom. Horizontal screws (T4–T5 top edge) are numbered left → right. T1–T11 are as-built on the populated unit. Float rails: top + is +12V_GD, bottom + is +5V_ISO, both − rails share −70V. On-board jumper paths and pin-by-pin IC wiring stay out of scope here; see Motor_Driver_Wiring.md.

Two galvanic domains. Columns 1–5 are the earth LED island: PWM, DIR, and MCU_GND from Board A (T-Display-S3 GPIO16 / GPIO21 and earth return). Those nets are earth-referenced only. Columns 6– 30 are floating, referenced to −70V. U1 and U4 translate the command signals optically; no copper joins the domains. Never tie MCU_GND to −70V. After HDR-15-5 #2 and HDR-15-12 negatives bond to −70V, treat both floating supplies as hazardous relative to earth. Do not clip an earth-referenced scope ground to −70V, the gate node, or SW.

### 1. Placement

View the board from above with U1 on the left and U4 on the right, as in the as-built photo. U3 (TC4426) sits in the center gutter; Q2 is beside U3; Q3 is beside U4. The isolation barrier falls at approximately column 5: a physical break in the proto buses separates the earth LED island from the floating region. The upper-left corner holds a vertical 3-position block (T1–T3). The earth-side Board A cable lands on T4 (PWM) and T5 (MCU_GND). The lower-left stack (T6–T7) carries HDR-15-5 #2. The upper-right block (T8–T9) takes DIR from Board A and drives PWM out to Board C. The lower-right block (T10–T11) wires the Phoenix K1 coil.

Private Reserve · Wiring Guide | 9 / 19

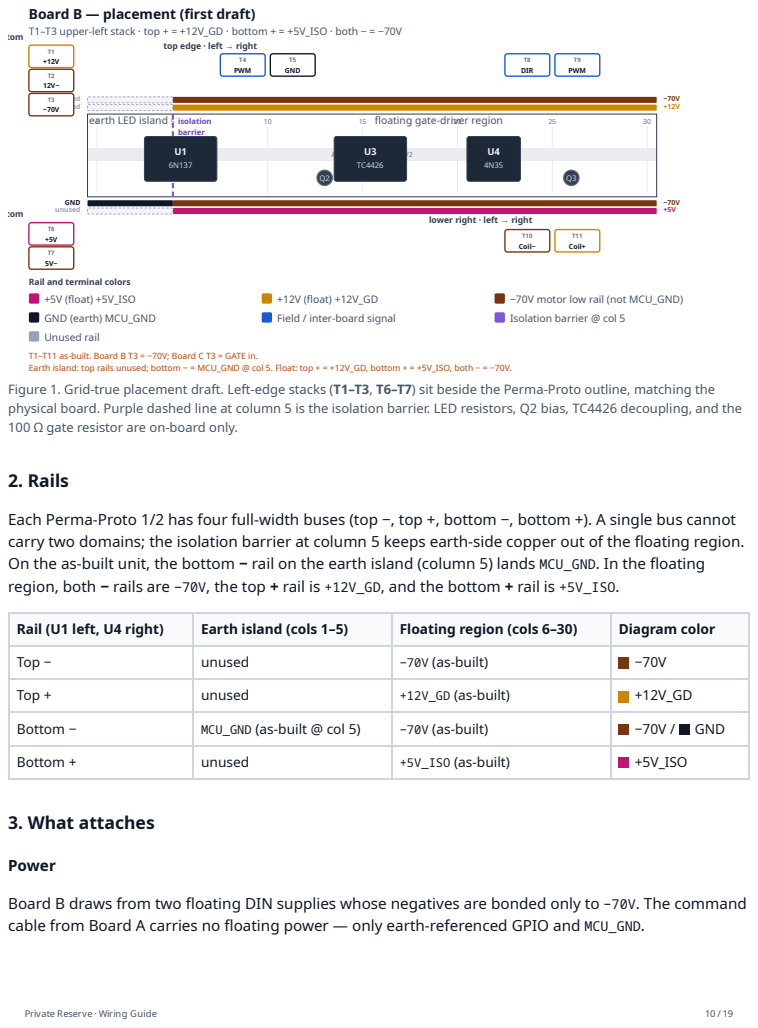
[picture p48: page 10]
unused unused; GND; unused; isolation barrier; earth LED island; floating gate-driver region; T4 PWM; T5 GND; T8 DIR; T9 PWM; tom; T10 Coil−; T11 Coil+; +5V (float) +5V_ISO; +12V (float) +12V_GD; −70V motor low rail (not MCU_GND); GND (earth) MCU_GND; Field / inter-board signal; Isolation barrier @ col 5; 2. Rails; 3. What attaches; Private Reserve · Wiring Guide

Board B — placement (first draft)
T1–T3 upper-left stack · top + = +12V_GD · bottom + = +5V_ISO · both − = −70V
tom

top edge · left → right

Adafruit Perma-Proto 1/2

lower right · left → right

Rail and terminal colors
Unused rail
T1–T11 as-built. Board B T3 = −70V; Board C T3 = GATE in.
Earth island: top rails unused; bottom − = MCU_GND @ col 5. Float: top + = +12V_GD, bottom + = +5V_ISO, both − = −70V.
Figure 1. Grid-true placement draft. Left-edge stacks (T1–T3, T6–T7) sit beside the Perma-Proto outline, matching the
physical board. Purple dashed line at column 5 is the isolation barrier. LED resistors, Q2 bias, TC4426 decoupling, and the
100 Ω gate resistor are on-board only.

Each Perma-Proto 1/2 has four full-width buses (top −, top +, bottom −, bottom +). A single bus cannot
carry two domains; the isolation barrier at column 5 keeps earth-side copper out of the floating region.
On the as-built unit, the bottom − rail on the earth island (column 5) lands MCU_GND. In the floating
region, both − rails are −70V, the top + rail is +12V_GD, and the bottom + rail is +5V_ISO.

Rail (U1 left, U4 right) | Earth island (cols 1–5) | Floating region (cols 6–30) | Diagram color
Top − | unused | −70V (as-built) | −70V
Top + | unused | +12V_GD (as-built) | +12V_GD
Bottom − | MCU_GND (as-built @ col 5) | −70V (as-built) | −70V / GND
Bottom + | unused | +5V_ISO (as-built) | +5V_ISO

Power
Board B draws from two floating DIN supplies whose negatives are bonded only to −70V. The command
cable from Board A carries no floating power — only earth-referenced GPIO and MCU_GND.

Land Mean Well HDR-15-12 on the upper-left stack: positive on T1 (+12V_GD) and negative on T2 (12 V supply return — bonded to −70V, not MCU_GND). That feed drives the top + rail (U3 VDD, Q2 bias, K1 coil branch).
Land Mean Well HDR-15-5 #2 on the lower-left stack: positive on T6 (+5V_ISO, top screw) and negative on T7 (bottom screw — floating return bonded to −70V, not MCU_GND) → bottom + rail → U1 VCC and VE. Do not connect either floating supply negative to MCU_GND or protective earth.

T3 (Board B) is the −70V landing for the short harness to Board C (Q1 source / U3 GND return). Do not confuse it with Board C T3, which receives PWM from Board B T9.

Screw terminals

Numbering follows Figure 1. Vertical stacks are top → bottom; horizontal screws are left → right on that edge.

Upper left — T1–T3 (top → bottom, as-built)

Terminal | Label | Net | Attaches
T1 | +12V | +12V_GD | Power in. Mean Well HDR-15-12 (+) → top + rail
T2 | 12V− | −70V | Power in. Mean Well HDR-15-12 (−). Floating supply return bonded to −70V. This is not MCU_GND.
T3 | −70V | −70V | Board B → Board C shared motor low rail (Q1 source / U3 pin 3). Keep this link short.

Top edge — T4–T5 (left → right, as-built)

Terminal | Label | Net | Attaches
T4 | PWM | PWM (GPIO16) | Board A T5 ← T-Display-S3 GPIO16. Earth island only → U1 LED through 220 Ω on-board. Optically isolated to the floating domain.
T5 | GND | MCU_GND | Board A T12 ← T-Display earth return. U1 / U4 LED cathodes. Never tie to −70V or floating supplies.

Lower left — T6–T7 (top → bottom, as-built)

Terminal | Label | Net | Attaches
T6 | +5V | +5V_ISO | Power in. Mean Well HDR-15-5 #2 (+) → bottom + rail → U1 VCC / VE
T7 | 5V− | −70V | Power in. Mean Well HDR-15-5 #2 (−). Floating supply return bonded to −70V. Not MCU_GND.

Upper right — T8–T9 (left → right, as-built)

Private Reserve · Wiring Guide | 11 / 19

Terminal | Label | Net | Attaches
T8 | DIR | DIR (GPIO21) | Board A T6 ← T-Display-S3 GPIO21. Earth island → U4 LED (270 Ω on-board). LED return shares T5 MCU_GND — no separate earth screw for DIR. Optically isolated to Q3 / K1 coil.
T9 | PWM out | PWM / gate | TC4426 OUT B through 100 Ω (on-board) → Board C T3. Floating domain. Return via Board B T3 −70V. Keep harness short.

Lower right — T10–T11 (left → right, as-built)

Terminal | Label | Net | Attaches
T10 | Coil− | K1 coil (−) / Q3 drain | Phoenix PLC-RSC-12DC/21-21 coil (−) via field wire. Low side switched by Q3 to −70V on-board.
T11 | Coil+ | +12V_GD | Phoenix K1 coil (+) from +12V_GD rail (HDR-15-12 / top + bus). D5 flyback (1N4007) is installed across these terminals on the as-built unit; cathode/band toward T11.

K1 coil (on-board driver, DIN relay)

Q3 switches the Phoenix K1 coil low-side on the floating domain. Field wires to the DIN relay coil land on T10 (Coil−) and T11 (Coil+). Do not route coil current through the Board B → Board C PWM link (T9).

Signal | Net | Attaches
K1 coil + | +12V_GD | T11 → Phoenix PLC-RSC-12DC/21-21 coil (+)
K1 coil − | Q3 drain | T10 ← relay coil (−); Q3 source → −70V
PWM command | PWM | T-Display-S3 GPIO16 → Board A T5 → Board B T4 → U1 LED (220 Ω on-board); optically isolated to Q2 / U3 / gate
Direction command | DIR | T-Display-S3 GPIO21 → Board A T6 → Board B T8 → U4 LED; return via T5 MCU_GND

Coil and contact detail: K1 floating coil option.

On-board only (not on screw terminals)

These subsystems stay on the Perma-Proto and are wired per Motor_Driver_Wiring.md:

U1 6N137 — PWM isolation; pin 6 → Q2 base
Q2 PN2222A — fail-off inverter (Rb2, Rbe2, Rc2 on-board)
U3 TC4426 — dual inverting gate driver; OUT B → 100 Ω → Board C gate path
U4 4N35 + Q3 2N7000TA — direction opto and coil low-side switch
220 Ω (U1 LED) and 270 Ω (U4 LED) beside the optocouplers
U3 decoupling: 100 nF, 1 µF across pins 6–3; 47 µF bulk nearby
Private Reserve · Wiring Guide | 12 / 19

Inter-board cables

Cable | Board B landing | Domain
Board A → Board B | T4 (PWM in), T5 (MCU_GND), T8 (DIR) | Earth only; translated optically by U1 / U4
Board B → Board C | T3 (−70V) + T9 (PWM out → Board C T3) | Floating; keep short
Board B → DIN K1 coil | T10 (Coil−), T11 (Coil+ / +12V_GD) | Floating

### 4. As-built photo

Line art is the labeled figure. The photo shows the unit that was built.

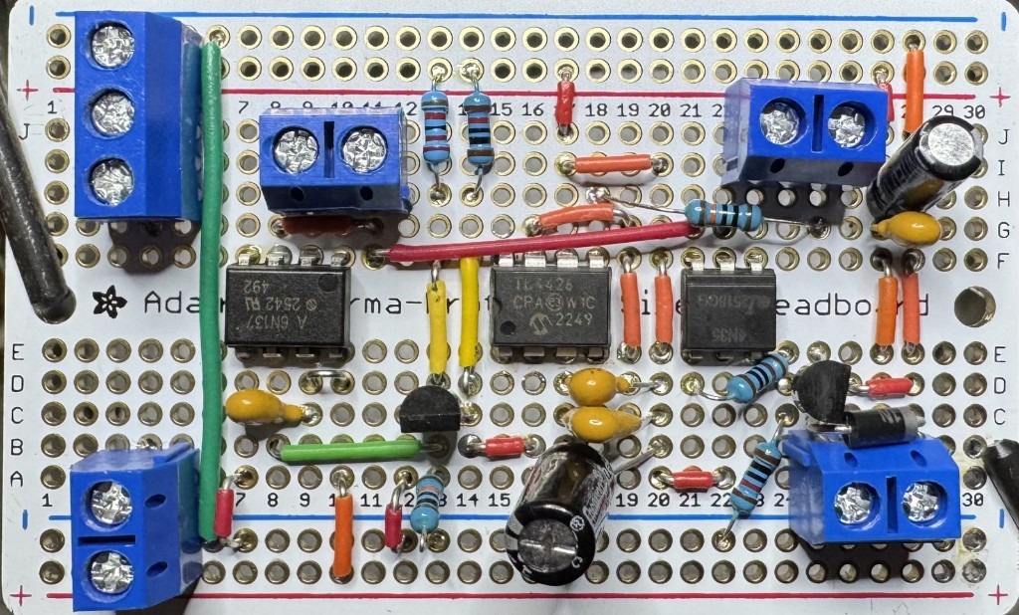
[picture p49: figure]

Populated carrier. U1 (6N137) on the left, U3 (TC4426) in the center, U4 (4N35) on the right. Isolation barrier at column 5.

Private Reserve · Wiring Guide | 13 / 19

Private Reserve · DIN controller · first draft

## Board C — HV switch stage

Adafruit Perma-Proto 1/4 (columns 1–15) carrying Q1 IRFP460, D9 STTH8R06 flyback, TVS1 P6KE200A, and the local SW / flyback loop. All copper is in the floating HV domain referenced to −70V. Screw terminals T4 and T5 wire to the DIN K1 return contacts; motor leads land on K1 COM, not on this board.

Draft. View with the screw terminals on the bottom edge and the IRFP460 heatsink at the top. Terminals are numbered T1–T5 left to right (T1 at column 3). On the as-built unit all four Perma-Proto power rails are unused — HV nets use column jumpers, not the silkscreen ± buses. On-board gate clamp parts (10 kΩ, BZX85C15) and row-column routing are documented elsewhere. Pin-by-pin IC wiring is not duplicated here.

Floating HV — up to 140 VDC. Every net on Board C is hazardous relative to earth when the motor supply is energized. −70V is not MCU_GND. Do not bond this board to protective earth except through an analyzed heatsink isolator. Q1 tab and drain are live at SW. Use an isolated or differential probe referenced to −70V, not earth ground. Discharge the bus and verify safe voltage before service.

### 1. Placement

Mount on DIN rail with ≥20 mm clearance beside the heatsink for airflow (see DIN layout). Q1 sits under an insulated heatsink at the top of the proto. D9 spans the mid board with cathode toward the fused +70V side and anode to SW. TVS1 clamps between the on-board +70V and −70V nodes (via column wiring, not the Perma-Proto rails). Five screw terminals on the bottom edge accept field and inter-board cables; there are no terminals on the top edge.

Flyback loop constraint. When Q1 turns off, motor inductance pushes current through D9 from SW to +70V. That path — SW → D9 anode → D9 cathode → +70V — must stay physically short and entirely on Board C. Figure 1 shows this as a dashed callout box below the proto; it is a placement rule, not a specific jumper wire to install. Do not run the flyback loop through a long cable to Board B or the DIN rail.

Private Reserve · Wiring Guide | 14 / 19

Board C — placement (first draft)
Heatsink up · terminals down · floating HV only · cols 1–15

unused
unused
1 | 5 10 | 15
D9 | Adafruit Perma-Proto 1/4 · cols 1–15 STTH8R06 · K→+70V · A→SW | band

unused
unused

heatsink (insulate tab)

Q1 IRFP460
G · D/SW · S/−70V

TVS1
P6KE200A
K→+70V · A→−70V
Rgs 10 kΩ | Dz BZX85C15
Gate network at Q1 (100 Ω may be on Board B)

Flyback loop
Placement rule — not a wire path
SW | → | D9 | → +70V

When Q1 turns off, motor inductance pushes current through D9. Path: SW → D9 anode → D9 cathode → +70V.
Keep D9 physically close to the SW node and +70V landing.
Do not route this flyback loop off Board C.

BOTTOM edge · left → right

T1
| | +70V

T2
−70V

T3
GATE

T4
NC1

T5
NO2

Net colors
+70V fused high rail | −70V motor low / Q1 source
SW — K1 NC1 / NO2 (T4 / T5) | GATE from Board B TC4426
Dashed box = placement rule (not a net) | Unused Perma-Proto rail

Draft. All four Perma-Proto rails are unused on the as-built unit. T4/T5 land K1 return contacts (NC1/NO2); motor leads are on K1 COM. As-built: T1/T2/T4/T5 leads are reinforced for motor current; T3 is gate only.
Never join MCU_GND to −70V. Q1 tab is live at SW — insulate the heatsink.

Figure 1. Grid-true placement (columns 1–15). Terminal IDs T1–T5 label each screw block left to right. Dashed gray bars are unused Perma-Proto rails. T4 and T5 are separate K1 return-contact landings (NC1 / NO2), both on the SW net on-

Private Reserve · Wiring Guide | 15 / 19

board. The full-width dashed amber box below the proto is a placement constraint for the flyback path — not a wire diagram.

### 2. Rails

The 1/4 Perma-Proto has four full-width buses (15 columns). On the as-built unit all four rails are unused — no jumpers connect them to +70V, −70V, or any other net. HV distribution uses column strips and point-to-point jumpers instead. Do not land MCU_GND, +5V_EARTH, +5V_ISO, or +12V_GD on any Board C bus.

Rail | Net | Diagram color
Upper outer − | unused (as-built; no jumper) | unused
Upper inner + | unused (as-built; no jumper) | unused
Lower inner − | unused (as-built; no jumper) | unused
Lower outer + | unused (as-built; no jumper) | unused

### 3. What attaches

Power

Board C receives the motor outer rails from the inter-box 140 V feed and Wago distribution (see DIN layout, row B). AnTek +70V is interlocked in the PSU box (AC-in and DC-out relays, coils on +12V_GD) before that feed reaches F1, the Wago star, K1, and T1. Run those coil leads in the AC inter-box passage, not beside the ±70 V PWM pair. Details: DIN enclosure — 140 V interlock relays. The fused +70V high rail enters at T1 after that interlock and F1. The low outer rail −70V enters at T2. Those terminals feed D9 cathode, TVS1, and Q1 source on-board. K1 high-side contacts (NO1/NC2) take fused +70V from the Wago star, not through a second Board C terminal, unless your harness branches from T1.

Screw terminals

Numbering follows Figure 1: left to right with the heatsink up and terminals down. T1 is leftmost (column 3 on the as-built unit). On the as-built board, leads at the motor-current terminals (T1, T2, T4, T5) are reinforced for the higher continuous and PWM motor current. Use heavy-gauge, HV-rated wire on those paths; keep T3 (gate) as a low-current signal lead. See DIN layout for 140 V path gauge guidance (18 AWG minimum; 16 AWG preferred for runs >1 m).

Bottom edge — T1–T5

Private Reserve · Wiring Guide | 16 / 19

Terminal | Label | Net | Attaches
T1 | +70V | +70V | Power in. After PSU-box DC interlock, then F1 / Wago → D9 K, TVS1 K (board-internal)
T2 | −70V | −70V | Power in. Motor low outer rail → Q1 source, TVS1 A, Rgs/Dz return (board-internal)
T3 | GATE | gate | Board B TC4426 OUT B (100 Ω may be on B or at Q1; see Motor_Driver_Wiring.md)
T4 | NC1 | SW | K1 pin 12 (NC1) — return contact → Q1 drain / D9 anode on-board
T5 | NO2 | SW | K1 pin 24 (NO2) — return contact → same SW node as T4 on-board

On-board only (not on terminals)

Ref | Part | Notes
Q1 | IRFP460NPBF | Low-side switch; tab = drain = SW
D9 | STTH8R06D | Motor PWM flyback; cathode → +70V, anode → SW
TVS1 | P6KE200A | Across +70V and −70V on-board (column wiring; rails unused)
Rgs | 10 kΩ | Gate-to-source at Q1
Dz | BZX85C15 | 15 V gate clamp at Q1

Full pin tables: Motor_Driver_Wiring.md.

Board B → Board C

Keyed two-conductor floating cable from Board B T9 (PWM out / gate) and T3 (−70V gate-driver return / Q1 source reference) to Board C T3 (GATE) and T2 (−70V). Keep this harness short; do not route the D9 flyback loop off Board C.

Board C → DIN K1 (contacts)

Direction switching uses the Phoenix K1 DPDT on the DIN rail. Board C lands the return-contact harness; high-side contacts and motor commons wire at the relay.

K1 pin | Net | From
NO1, NC2 | +70V (fused) | Wago / F1 star (not a Board C terminal unless branched from T1)
NC1 (12) | SW | T4
NO2 (24) | SW | T5
COM1, COM2 | MOTOR_A, MOTOR_B | Field motor harness (HV gland)

K1 coil (+12V_GD / Q3) is driven from Board B; see K1 floating coil option.

Private Reserve · Wiring Guide | 17 / 19

### 4. As-built photo

Line art is the labeled figure. The photo shows the unit that was built.

Private Reserve · Wiring Guide | 18 / 19

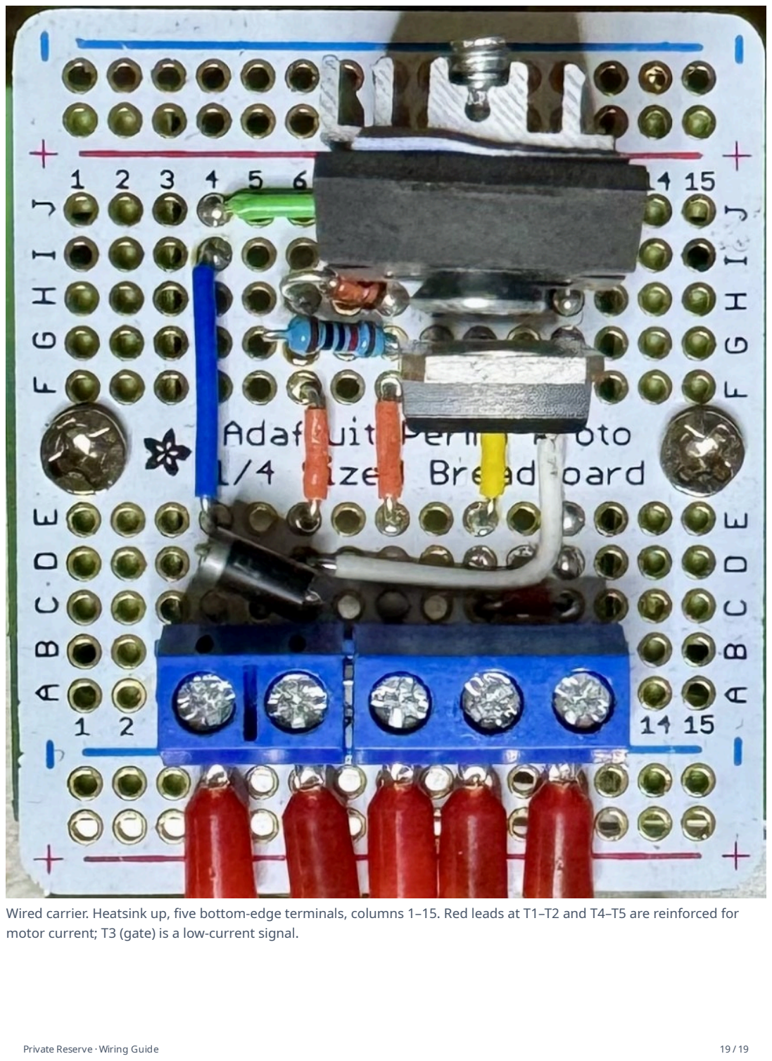
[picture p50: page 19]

Wired carrier. Heatsink up, five bottom-edge terminals, columns 1–15. Red leads at T1–T2 and T4–T5 are reinforced for motor current; T3 (gate) is a low-current signal.

Private Reserve · Wiring Guide | 19 / 19

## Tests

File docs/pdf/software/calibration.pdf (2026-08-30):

Private Reserve · DIN controller · first draft

# Calibration

Initial setup and later recals. A full first run does every stage. A later run can open one process. Header prefix is CAL ·.

Draft. Pixel layout: UI/calibration.html. Hardware procedures: Limit_Marker_And_Snug.md, Load_Bin_Obstruction_Calibration.md.

The door will move. Path-clear must pass before any stage that commands the motor. There is no physical E-stop. HOLD cancels: PWM off, wait for current decay, leave K1 unchanged, discard the partial result, return to the stage list. Never write NVS mid-motion. Review is the single save.

Private Reserve · Software User Manual · Calibration | 1 / 16

### 1. Stage list

Entry for a full setup and for a single recalibration. Status words name stale or missing work so you do not run a later stage on a bad earlier one. Six compact rows fit. TURN windows the list. Door-physics stages come first. The bottle key is last, before Review.


Figure 1. CAL · stages. Stroke entry selected. Stages 7–8 blocked until stroke exists.

Private Reserve · Software User Manual · Calibration | 2 / 16

On screen | Meaning
CAL · stages | Header left. Calibration mode, stage list.
1–6 of 10 ▾ | Header right. Window into nine capture stages plus Review.
Green pip + 1 · Baselines (current, shaft) + DONE | Stage 1 complete. Two rest captures used by motion: ACS712 zero and AS5600 jitter.
Green pip + 2 · Direction verify + MATCH | Commanded direction agreed with the shaft. Invert flag is good. Gates all seeks.
Green pip + 3 · Open marker → origin + ± 6 CNT | Open-edge probes accepted. Spread across repeats is 6 counts. That edge is count 0.
Green pip + 4 · Close marker → span + ± 9 CNT | Close-edge probes accepted. Spread 9 counts. Edge minus origin is the measured span.
Green pip + 5 · Closed seated + BY CURRENT | Seated found by current rise, not stall. Confirmation, not a home.
Amber pip + highlight + 6 · Stroke entry + NEEDED | Selected row. Operator inches are missing. Required before learn runs, not before marker seeks.
Grey pip + 9 · Obstruction table — empty + BLOCKED | Cannot start until stroke and Door pace exist. Empty-rack learn at the selected pace. Stages 7–8 are spring take-up and Door pace.
Grey pip + 8 · Obstruction table — loaded + OPTIONAL | Second table with racks at max expected load. Skip is allowed.
9 · Bottle door key — 49E | Present and absent levels. After the learn runs so the first pass can stay on door physics.
TURN scroll | Move the highlight. Window the list if more rows exist than fit.
PRESS open | Enter the highlighted stage. Moving stages show path-clear first.
HOLD exit | Return to Main. Incomplete RAM results stay until Review saves or you discard them there.
Private Reserve · Software User Manual · Calibration | 3 / 16

### 2. Path-clear gate

Shown before any stage that commands the motor. A checklist, not a single OK. The door does not move until every line is ticked.

Figure 2. CAL · confirm, before stage 3. Third line still unticked.

On screen | Meaning
CAL · confirm | Header left. Gate, not a capture screen.
before stage 3 | Header right. This shot is the gate for open-marker seek. Other moving stages show their own number.
THE DOOR WILL MOVE | Amber banner title. Condition before command.
140 V motor · no physical E-stop installed | Banner detail. HOLD is the only cancel. There is no E-stop on this build.
Green pip + Travel path clear of tools and people | Ticked. Operator has acknowledged a clear path.
Green pip + Both marker switches wired and reading LOW | Ticked. NC markers at rest read LOW on this polarity. A HIGH rest would mean a cut wire or a made switch.
Grey pip + highlight + Racks empty for this stage | Not yet ticked. Selected line. TURN moves among lines. This line appears when the stage requires empty racks.
TURN tick | Toggle the highlighted checklist line.
PRESS start | Start the stage when every line is ticked. Does nothing while a line is still grey.
HOLD cancel | Return to the stage list. No motion.
Private Reserve · Software User Manual · Calibration | 4 / 16

### 3. Stage 1a — current zero

Captured with PWM at zero. ACS712 offset only. It shares nothing with the shaft or key baselines.

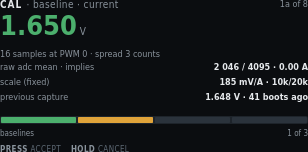
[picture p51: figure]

Figure 3. CAL · baseline · current. Motor at rest.

On screen | Meaning
CAL · baseline · current | Header left. First of three baseline captures.
1a of 9 | Header right. Stage 1, first sensor, of nine stages.
1.650 V (green) | Hero. Mean ACS712 output at PWM 0. Green means the spread is acceptable.
16 samples at PWM 0 · spread 3 counts | How the mean was taken. Spread is ADC counts, not amps.
raw adc mean · implies · 2 046 / 4095 · 0.00 A | Raw mean of 4095, and the cooked amp reading that offset implies (zero at rest).
scale (fixed) · 185 mV/A · 10k/20k | ACS712-05B sensitivity and the Board A divider. Not an operator edit.
previous capture · 1.648 V · 41 boots ago | Last stored zero, for comparison. No RTC. Age is boot count.
Progress bar, first segment amber, baselines · 1 of 2 | Two motion baselines. This is current zero. Shaft jitter is next.
PRESS accept | Keep this zero in RAM and go to shaft jitter.
HOLD cancel | Discard this capture. Return to the stage list.
Private Reserve · Software User Manual · Calibration | 5 / 16

### 4. Stage 1b — shaft jitter band

Measured at rest. This band sets stall minimum progress and the accumulation deadband.


Figure 4. CAL · baseline · shaft. Rest jitter over 2.0 s.

On screen | Meaning
CAL · baseline · shaft | Header left. Second baseline.
1b of 9 | Header right.
± 3 cnt (green) | Hero. Peak-to-peak AS5600 counts at rest.
peak-to-peak at rest · 2.0 s window | How long the band was watched.
samples · magnet · I2C ACK · detected | Bus then STATUS. I2C ACK means the chip answered. detected / lost / too weak / too strong is magnet quality. I2C NACK plus unread means the bus failed.
sets stall minimum progress · 8 cnt / 500 ms | Stall check needs more motion than rest jitter. Derived from this band, not guessed.
sets accumulation deadband · 3 cnt | Counts inside this band do not walk idle position.
Progress, one green + one amber, baselines · 2 of 2 | Current zero accepted. Shaft is the last motion baseline. The bottle key is stage 9.
PRESS accept · HOLD cancel | Keep the band, or discard and return to the list.
Private Reserve · Software User Manual · Calibration | 6 / 16

### 5. Stage 2 — direction verify

Runs before any seek. A wrong invert flag would send the first seek at the far end of travel. Slow duty, short move. The operator confirms the door went the way the screen says.

Figure 6. CAL · direction. Match. Invert is unchanged.

On screen | Meaning
CAL · direction | Header left.
2 of 9 | Header right.
MATCH (green) | Hero. Commanded OPEN and the shaft turned the expected way.
commanded OPEN · shaft turned CCW | What firmware asked and what the encoder saw.
+412 cnt | Net counts during the short move.
duty 96 · 1.4 s | Creep duty and how long the probe ran.
invert flag · false (unchanged) | Mapping of K1 to shaft sense. False means the compiled default already matches this cabinet.
current during move · 0.62 A peak | Peak amps on this short move. A stall here is a wiring or bind problem, not a direction problem.
door moved toward · OPEN — confirm on the door | Look at the physical door. The encoder can match a wrong invert if you never look.
Amber line: If the door moved to CLOSE, press to set the invert flag and repeat. | Mismatch path. PRESS sets invert and runs the probe again.
PRESS invert | Flip the invert flag and repeat the short move.
TURN accept | Keep MATCH (or the new invert after a repeat).
HOLD cancel | Discard. Return to the stage list.
Private Reserve · Software User Manual · Calibration | 7 / 16

### 6. Stage 3 — open marker and origin

Repeat probes of the same edge from the same direction. The spread is the pass criterion. The accepted actuation edge becomes count zero.

Figure 7. CAL · open marker. Third probe complete. Spread 6 counts.

On screen | Meaning
CAL · open marker | Header left.
3 of 9 | Header right.
PROBE 3 / 3 (amber) | Hero. Last of three approaches. Amber because the motor just moved.
creep · back off 400 cnt · re-approach | Probe method. Operational snug does not apply during calibration seeks.
probe 1 — actuate / release · 402 / 361 cnt | First pair. Actuation and release differ because the switch has hysteresis. Approach from the same direction each time.
probe 2 — actuate / release · 398 / 358 cnt | Second pair.
probe 3 — actuate / release · 404 / 363 cnt | Third pair.
spread · tolerance · 6 · 20 cnt | Actuate spread across repeats versus the allowed band. 6 is inside 20.
origin will be set at · actuate edge → 0 | Accepted open actuation becomes count zero for everything downstream.
PRESS accept origin | Keep the origin in RAM.
HOLD cancel | Discard a half-probed edge. Partial marker data is not usable.
Private Reserve · Software User Manual · Calibration | 8 / 16

### 7. Stage 4 — close marker and span

Same probe method at the other end. The accepted edge minus origin is the measured span. Obstruction bins divide this span.

Figure 8. CAL · close marker. Measured span accepted if you press.

On screen | Meaning
CAL · close marker | Header left.
4 of 9 | Header right.
20 180 cnt (green) | Hero. Measured span from origin to close actuation.
measured span · origin to close actuate | What the hero number is. Not seated. Seated is stage 5, past this edge.
probe 1 / 2 / 3 actuate · 20 174 / 20 183 / 20 180 | Three actuation edges. Release edges were captured. This row shows actuate only.
spread · tolerance · 9 · 20 cnt | Spread inside tolerance.
implies shaft revolutions · 4.93 rev | Span divided by 4096 counts/rev. Sanity check against the mechanical stroke.
bin width at 81 bins · 249 cnt | Span divided into 81 obstruction bins.
Progress, three green, close probes · 3 of 3 | All three close probes done.
PRESS accept span · HOLD cancel | Keep the span, or discard the half-probed edge.
Private Reserve · Software User Manual · Calibration | 9 / 16

### 8. Stage 5 — closed seated

Past the close marker on creep. How the stop was found is stored: a current rise means the seal is loading. A stall without one means the door hit something solid.

Figure 9. CAL · closed seated. Found by current rise, 168 counts past the marker.

On screen | Meaning
CAL · closed seated | Header left.
5 of 9 | Header right.
SEATED (green) | Hero. Physical closed stop found.
found by CURRENT RISE at 1.90 A | Method. Prefer current-draw rise (snug). Else record stall.
+168 cnt | Counts past the close-marker actuation.
past close marker | Seated is beyond the near-end flag, not at it.
method stored · current rise (not stall) | Written with the capture so Diagnostics can show why seated was accepted.
creep duty · timeout · 96 · 1.4 s of 2.0 s | Duty used and how much of the seek timeout was consumed.
overtravel cap · 220 cnt — not reached | Hard cap past the marker. A hit here is a fault, not a seated capture.
seated position · 20 348 cnt | Origin-relative counts of the seated stop.
Green line: Seated is a confirmation, not a position reference. Re-homing uses the marker edges. | Do not treat seated as a home. Power-loss recovery seeks the open marker.
PRESS accept · HOLD cancel | Keep seated, or discard.
Private Reserve · Software User Manual · Calibration | 10 / 16

### 9. Stage 6 — stroke entry

The only operator-typed number, and the only place inches enter the system. It gates learn runs because bin widths are reported in centimetres. It never widens a safety limit.

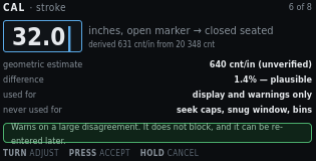
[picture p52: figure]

Figure 10. CAL · stroke. 32.0 in, derived 631 cnt/in.

On screen | Meaning
CAL · stroke | Header left.
6 of 9 | Header right.
Integer inches, then 1/16 | TURN ±1 in, PRESS sixteenths, TURN ±1/16. Fractions reduce (1/2 not 8/16).
inches, open marker → close marker | Tape the two limit switches. Not seated, not cabinet width.
derived 631 cnt/in from 20 348 cnt | Seated counts divided by the typed inches. Display only.
geometric estimate · 640 cnt/in (unverified) | Independent estimate from the mechanical drawing. Unverified means it is not a measured fact.
difference · 1.4% — plausible | Typed stroke versus the geometric estimate. A large disagreement warns. It does not block.
used for · display and warnings only | Inches and counts-per-inch never feed a seek cap.
never used for · seek caps, snug window, bins | Those limits stay in counts from stages 3–5.
Green line: Warns on a large disagreement. It does not block, and it can be re-entered later. | You can fix a typo without repeating marker probes.
TURN adjust | Change the pending inches.
PRESS accept | Keep the stroke in RAM. Unblocks stage 7.
HOLD cancel | Leave the previous stroke (or none).
Private Reserve · Software User Manual · Calibration | 11 / 16

### 10. Stage 7 — obstruction table, empty racks

Three clear runs each way at the production profile. Obstruction reverse is off. The 2.50 A ceiling stays on. A trip discards that run instead of teaching it.

Figure 11. CAL · learn · empty. Second close run in cruise.

On screen | Meaning
CAL · learn · empty | Header left. Empty-rack table.
7 of 9 | Header right.
CLOSE RUN 2 (amber) | Hero. Second of three close strokes. Motor live.
cruise · bin 44 of 81 · 1.38 A | Profile phase, current bin, live amps.
74 / 81 | Bins that already have a valid sample this run set.
bins valid | Learn runs stop at the marker, so some end bins stay unvisited.
Open-run pips, two green + one amber, open runs · 2 of 3 | Open-direction progress. This shot is mid close-run, so the open bar may already be ahead.
Close-run pips, one green + one amber + one grey, close runs · 1 of 3 | Close-direction progress. Run 2 is live.
profile identity · 512 · 3000/6000/3000 ms | Cruise duty and accel / cruise / decel times. Stored with the table so a later profile change can invalidate it.
reverse off · ceiling armed · learn mode · 2.50 A | Obstruction reverse is off so a bind is not taught as load. The hard ceiling still trips and discards the run.
HOLD cancel run set | PWM off, current decay, K1 unchanged, discard the incomplete table. Return to the stage list. There is no PRESS on this live run.
Private Reserve · Software User Manual · Calibration | 12 / 16

### 11. Stage 8 — obstruction table, loaded racks

Optional second table with racks at maximum expected load. Which table arms in service is still an open spec decision, so the screen states it.

Figure 12. CAL · learn · loaded. Gate before the loaded run set.

On screen | Meaning
CAL · learn · loaded | Header left.
8 of 9 | Header right.
LOAD THE RACKS | Amber banner title. Do not start this set empty.
Fill to maximum expected capacity before starting this set | Banner detail. Max expected load, not an overload test.
empty table · stored · armed | Stage 7 already produced a usable empty-rack envelope.
loaded table · not yet learned | This stage has not run.
arming rule · undecided — see spec | Which table Main uses in service is not chosen on this panel. See Production_Software.md.
runs required · 3 open · 3 close | Same run count as the empty table.
PRESS start | After racks are loaded, start the run set (path-clear still applies).
HOLD skip | Leave the loaded table unlearned. Review will show it as optional skipped.
Private Reserve · Software User Manual · Calibration | 13 / 16

### 12. Stage 9 — bottle key levels

Last capture before Review. Two captures: bottle out, then bottle in. Enter and exit thresholds are derived from the gap. The door does not move. Path-clear is not shown.

Figure 5. CAL · bottle key. Second capture, bottle in the recess. Live header is 9 of 9.

On screen | Meaning
CAL · bottle key | Header left. After the learn runs.
9 of 9 | Header right. Last guided capture.
2 980 (green) | Hero. Present-level ADC this capture.
capture 2 of 2 — bottle IN the recess | Operator has placed the bottle. Capture 1 was absent.
absent 1 605 | Right of the hero. First capture, bottle out.
captured 00:41 ago | Age of the absent capture this session.
gap between levels · 1 375 counts | Present minus absent. A small gap means a weak magnet or a bad placement.
derived enter / exit · dead zone · 2 400 / 2 100 · 300 | Hysteresis pair and the dead zone between them. Not a single threshold.
polarity for this build · absent → OPEN | Default handbook polarity. Place the bottle to close. Change it in Settings if this cabinet is wired the other way.
PRESS accept · HOLD cancel | Keep both levels, or discard.
Private Reserve · Software User Manual · Calibration | 14 / 16

### 13. Review and save

Single NVS write. Everything above lived in RAM until this screen. The blob carries the profile identity that will later invalidate it. Motor must be idle.

Figure 13. CAL · review. One optional stage skipped. Motor idle.

On screen | Meaning
CAL · review | Header left.
save | Header right. This is the write point.
READY TO SAVE (green) | Hero. Completeness check passed.
8 stages complete · 1 optional skipped | Loaded-rack table was skipped. Empty table is enough to leave Needs Setup.
origin · span · seated · 0 · 20 180 · 20 348 cnt | The three count references from stages 3–5.
marker spread (open / close) · 6 / 9 cnt | Probe quality from stages 3 and 4.
stroke → derived · 32.0 in → 631 cnt/in | Typed stroke and the display-only scale.
tables · blob · empty armed · v3 3.6 kB | Which envelope is armed, format version, and blob size.
Green line: Motor is idle and current has decayed. NVS is never written while the motor runs. | If the motor is still spinning, this screen will not write.
PRESS save | One NVS write. Then return toward Main.
HOLD discard | Drop the RAM results. Stored NVS is unchanged.

### 14. Knob on a live stage

Private Reserve · Software User Manual · Calibration | 15 / 16

Gesture | Typical meaning
TURN | Jog or adjust where the stage allows it (stroke entry, direction accept, checklist tick).
PRESS | Capture, accept, or start the next sample.
HOLD | Cancel the live procedure. Return to the stage list.

When an earlier value changes, mark dependent later steps stale. There is no RTC. Metadata uses run count and relative millis only. Never reverse K1 without PWM blanking.

### 15. Related

Software overview — full web UI, figure 1

This page is a chapter of the Software User Manual.

Private Reserve · Software User Manual · Calibration | 16 / 16

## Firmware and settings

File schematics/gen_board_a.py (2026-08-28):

#!/usr/bin/env python3
"""Generate Board_A.svg — earth-side T-Display-S3 service schematic."""

from pathlib import Path

OUT = Path(__file__).with_name("Board_A.svg")

# Columns: T1/T13 … T12/T24, left → right, USB-C nearest T1/T13
X0 = 102
PITCH = 108
XS = [X0 + i * PITCH for i in range(12)]

ON_X, ON_Y, ON_W = 40, 162, 1620
OFF_X, OFF_W = 1684, 556
BOX_GAP = 18

# Terminal strips
TOP_Y, TOP_H = 230, 86
BOT_Y, BOT_H = 1188, 92

# T-Display body (pins sit on the long edges)
DISP_X = XS[0] - 30
DISP_W = XS[-1] - XS[0] + 60
DISP_Y = 496
DISP_H = 260
Y_TOP_PIN = DISP_Y
Y_BOT_PIN = DISP_Y + DISP_H

Y33 = 340
YGND = 1096

LOWER_Y = Y_BOT_PIN + 12
LOWER_H = 612
ON_H = LOWER_Y + LOWER_H + BOX_GAP - ON_Y
W, H = 2280, ON_Y + ON_H + 80

C_V5 = "#b42318"
C_V33 = "#dc6803"
C_GND = "#101828"
C_IO = "#175cd3"
C_ENC = "#7f56d9"
C_NC = "#98a2b3"
C_INK = "#222"

KIND = {
    "v5": (C_V5, "v5"),
    "v33": (C_V33, "v33"),
    "gnd": (C_GND, "gnd"),
    "io": (C_IO, "earth"),
    "enc": (C_ENC, "enc"),
    "nc": (C_NC, "nc"),
}


def esc(s):
    return s.replace("&", "&amp;").replace("<", "&lt;").replace(">", "&gt;")


class Svg:
    def __init__(self):
        self.b = []

    def add(self, s):
        self.b.append(s)

    def line(self, x1, y1, x2, y2, cls):
        self.add(
            f'<line x1="{x1}" y1="{y1}" x2="{x2}" y2="{y2}" class="{cls}"/>'
        )

    def path(self, d, cls):
        self.add(f'<path d="{d}" class="{cls}"/>')

    def circle(self, x, y, r, fill):
        self.add(f'<circle cx="{x}" cy="{y}" r="{r}" fill="{fill}"/>')

    def text(self, x, y, cls, t, extra=""):
        self.add(
            f'<text x="{x}" y="{y}" class="{cls}"{extra}>{esc(t)}</text>'
        )

    def mid(self, x, y, cls, t):
        self.text(x, y, cls, t, ' text-anchor="middle"')

    def rect(self, x, y, w, h, cls, rx=5):
        self.add(
            f'<rect x="{x}" y="{y}" width="{w}" height="{h}" '
            f'rx="{rx}" class="{cls}"/>'
        )

    def stroke(self, x1, y1, x2, y2, color, sw=3):
        self.add(
            f'<line x1="{x1}" y1="{y1}" x2="{x2}" y2="{y2}" '
            f'stroke="{color}" stroke-width="{sw}" '
            f'stroke-linecap="round"/>'
        )

    def res_v(self, x, y, w, h, value):
        self.rect(x - w / 2, y, w, h, "part", rx=2)
        self.mid(x, y + h / 2 + 4, "pin", value)

    def hop_h(self, y, x0, x1, hop_xs, cls, color, r=8):
        hops = sorted(h for h in hop_xs if min(x0, x1) < h < max(x0, x1))
        step = 1 if x1 >= x0 else -1
        cur = x0
        for hx in hops if x1 >= x0 else reversed(hops):
            self.line(cur, y, hx - step * r, y, cls)
            x_a, x_b = hx - r, hx + r
            sweep = 1 if x1 >= x0 else 0
            self.add(
                f'<path d="M{x_a} {y} A{r} {r} 0 0 {sweep} {x_b} {y}" '
                f'fill="none" stroke="{color}" stroke-width="3"/>'
            )
            cur = hx + step * r
        self.line(cur, y, x1, y, cls)

    def hop_v(self, x, y0, y1, hop_ys, cls, color, r=8):
        hops = sorted(h for h in hop_ys if min(y0, y1) < h < max(y0, y1))
        step = 1 if y1 >= y0 else -1
        cur = y0
        for hy in hops if y1 >= y0 else reversed(hops):
            self.line(x, cur, x, hy - step * r, cls)
            y_a, y_b = hy - r, hy + r
            sweep = 1 if y1 >= y0 else 0
            self.add(
                f'<path d="M{x} {y_a} A{r} {r} 0 0 {sweep} {x} {y_b}" '
                f'fill="none" stroke="{color}" stroke-width="3"/>'
            )
            cur = hy + step * r
        self.line(x, cur, x, y1, cls)

    def out(self):
        return "\n".join(self.b)


# RIGHT header, pin 12 nearest USB (left). Display-up top edge.
TOP = [
    dict(t="T1", lab="3V", gpio="+3V3", kind="v33", dest="sensor VCC",
         pin=12, hdr="3V"),
    dict(t="T2", lab="GND", gpio="MCU_GND", kind="gnd", dest="returns",
         pin=11, hdr="GND"),
    dict(t="T3", lab="GND", gpio="MCU_GND", kind="gnd", dest="returns",
         pin=10, hdr="GND"),
    dict(t="T4", lab="NC", gpio="—", kind="nc", dest="unassigned",
         pin=9, hdr="NC", to_term=False),
    dict(t="T5", lab="PWM", gpio="GPIO16", kind="io", dest="→ B T4",
         pin=8, hdr="16"),
    dict(t="T6", lab="DIR", gpio="GPIO21", kind="io", dest="→ B T8",
         pin=7, hdr="21"),
    dict(t="T7", lab="LIM-U", gpio="GPIO17", kind="io", dest="upper NC",
         pin=6, hdr="17"),
    dict(t="T8", lab="CLOSE", gpio="GPIO18", kind="io", dest="rocker",
         pin=5, hdr="18"),
    dict(t="T9", lab="SCL", gpio="GPIO44", kind="io", dest="AS5600",
         pin=4, hdr="44"),
    dict(t="T10", lab="SDA", gpio="GPIO43", kind="io", dest="AS5600",
         pin=3, hdr="43"),
    dict(t="T11", lab="GND", gpio="MCU_GND", kind="gnd", dest="returns",
         pin=2, hdr="GND"),
    dict(t="T12", lab="GND", gpio="MCU_GND", kind="gnd", dest="→ B T5",
         pin=1, hdr="GND"),
]

# LEFT header, pin 12 nearest USB (left). Display-up bottom edge.
BOT = [
    dict(t="T13", lab="5V", gpio="+5V_EARTH", kind="v5", dest="HDR #1 +",
         pin=12, hdr="5V", to_term=True),
    dict(t="T14", lab="GND", gpio="MCU_GND", kind="gnd", dest="HDR #1 −",
         pin=11, hdr="GND", to_term=True),
    dict(t="T15", lab="5V", gpio="+5V_EARTH", kind="v5", dest="ACS712 VCC",
         pin=10, hdr="NC", hdr_kind="nc", to_term=False),
    dict(t="T16", lab="GND", gpio="MCU_GND", kind="gnd", dest="returns",
         pin=9, hdr="NC", hdr_kind="nc", to_term=False),
    dict(t="T17", lab="GND", gpio="MCU_GND", kind="gnd", dest="returns",
         pin=8, hdr="13", hdr_kind="enc", to_term=False),
    dict(t="T18", lab="GND", gpio="MCU_GND", kind="gnd", dest="returns",
         pin=7, hdr="12", hdr_kind="enc", to_term=False),
    dict(t="T19", lab="NC", gpio="GPIO11", kind="nc", dest="EC11 CLK on-bd",
         pin=6, hdr="11", hdr_kind="enc", to_term=False),
    dict(t="T20", lab="OPEN", gpio="GPIO10", kind="io", dest="rocker",
         pin=5, hdr="10", to_term=True),
    dict(t="T21", lab="LIM-L", gpio="GPIO3", kind="io", dest="lower NC",
         pin=4, hdr="3", to_term=True),
    dict(t="T22", lab="ISENSE", gpio="GPIO2", kind="io", dest="ACS712 OUT",
         pin=3, hdr="2", to_term=True),
    dict(t="T23", lab="HALL", gpio="GPIO1", kind="io", dest="SS49E OUT",
         pin=2, hdr="1", to_term=True),
    dict(t="T24", lab="3V", gpio="+3V3", kind="v33", dest="sensor VCC",
         pin=1, hdr="3V", to_term=True),
]


def build():
    s = Svg()
    a = s.add

    a(f'''<?xml version="1.0" encoding="UTF-8"?>
<svg xmlns="http://www.w3.org/2000/svg" width="{W}" height="{H}"
     viewBox="0 0 {W} {H}" version="1.1" role="img"
     aria-labelledby="title desc">
  <title id="title">Board A — Earth-side control</title>
  <desc id="desc">Service schematic for the Private Reserve Board A
    dual Perma-Proto 1/2. LilyGo T-Display-S3, on-board EC11, screw
    terminals T1–T24. Earth domain only.
  </desc>
  <defs>
    <style>
      .wire {{ fill:none; stroke:#222; stroke-width:3; stroke-linecap:round; stroke-linejoin:round }}
      .earth {{ fill:none; stroke:#175cd3; stroke-width:3; stroke-linecap:round; stroke-linejoin:round }}
      .gnd {{ fill:none; stroke:#101828; stroke-width:3; stroke-linecap:round; stroke-linejoin:round }}
      .v5 {{ fill:none; stroke:#b42318; stroke-width:4; stroke-linecap:round; stroke-linejoin:round }}
      .v33 {{ fill:none; stroke:#dc6803; stroke-width:3; stroke-linecap:round; stroke-linejoin:round }}
      .enc {{ fill:none; stroke:#7f56d9; stroke-width:3; stroke-linecap:round; stroke-linejoin:round }}
      .nc {{ fill:none; stroke:#98a2b3; stroke-width:2; stroke-dasharray:6 4; stroke-linecap:round }}
      .box {{ fill:#fff; stroke:#344054; stroke-width:2 }}
      .part {{ fill:#f9fafb; stroke:#344054; stroke-width:2 }}
      .onboard {{ fill:#fff; stroke:#344054; stroke-width:2.4 }}
      .earthbox {{ fill:#eff8ff; stroke:#175cd3; stroke-width:1.6 }}
      .off {{ fill:#f9fafb; stroke:#667085; stroke-width:2; stroke-dasharray:8 5 }}
      .warn {{ fill:#fffaeb; stroke:#dc6803; stroke-width:2 }}
      .termbox {{ fill:#fff; stroke:#344054; stroke-width:2 }}
      .termnc {{ fill:#f9fafb; stroke:#98a2b3; stroke-width:1.6; stroke-dasharray:5 3 }}
      .callout {{ fill:#fffaeb; stroke:#dc6803; stroke-width:1.6; stroke-dasharray:5 3 }}
      .lcd {{ fill:#1d2939; stroke:#344054; stroke-width:1.6 }}
      .title {{ font:700 26px sans-serif; fill:#101828 }}
      .section {{ font:700 16px sans-serif; fill:#101828 }}
      .label {{ font:600 15px sans-serif; fill:#101828 }}
      .text {{ font:14px sans-serif; fill:#344054 }}
      .small {{ font:12px sans-serif; fill:#475467 }}
      .pin {{ font:12px monospace; fill:#344054 }}
      .lcdtitle {{ font:700 16px sans-serif; fill:#f2f4f7 }}
      .lcdsub {{ font:11px sans-serif; fill:#d0d5dd }}
      .v5text {{ font:700 13px sans-serif; fill:#b42318 }}
      .v33text {{ font:700 13px sans-serif; fill:#dc6803 }}
      .gndtext {{ font:700 13px sans-serif; fill:#101828 }}
      .earthtext {{ font:700 13px sans-serif; fill:#175cd3 }}
      .enctext {{ font:700 12px sans-serif; fill:#6941c6 }}
      .nctext {{ font:700 12px sans-serif; fill:#667085 }}
    </style>
  </defs>''')

    s.rect(0, 0, W, H, "box", rx=0)
    a(f'<rect width="{W}" height="{H}" fill="#fff"/>')

    s.text(40, 40, "title", "Board A — Earth-side control")
    s.text(
        40,
        64,
        "text",
        "Private Reserve · as-built dual Adafruit Perma-Proto 1/2 · "
        "LilyGo T-Display-S3 + EC11 · T1–T24 · Rev 2026-08-27",
    )

    s.rect(40, 78, 2200, 68, "warn")
    s.text(56, 102, "label",
           "Earth domain only. Never land floating or HV copper here.")
    s.text(
        56,
        124,
        "text",
        "No +5V_ISO, +12V_GD, −70V, +70V, or SW. MCU_GND is not −70V. "
        "Do not back-feed 3.3 V into the module 3V pin. LED resistors stay "
        "on Board B.",
    )

    # ---- ON BOARD ----
    s.rect(ON_X, ON_Y, ON_W, ON_H, "onboard", rx=8)
    s.text(56, 186, "section", "BOARD A · on-board")
    s.text(
        280,
        186,
        "small",
        "Display facing you · USB-C left · EC11 right · header pin 12 "
        "nearest USB · upper outer rails unused · +5V_EARTH is not a proto + bus",
    )

    # Proto halves (light)
    s.rect(54, 198, 1548, DISP_Y - 198 - 8, "earthbox", rx=6)
    s.text(66, 216, "earthtext", "UPPER PERMA-PROTO 1/2")
    s.text(280, 216, "small",
           "row A takes the T-Display RIGHT header · top edge T1–T12 · pin 12 nearest USB")

    s.rect(54, LOWER_Y, 1548, LOWER_H, "earthbox", rx=6)
    s.text(66, Y_BOT_PIN + 32, "earthtext", "LOWER PERMA-PROTO 1/2")
    s.text(280, Y_BOT_PIN + 32, "small",
           "row J takes the T-Display LEFT header · bottom edge T13–T24 · pin 12 nearest USB")

    # ---- Top terminal strip T1–T12 ----
    strip_x = XS[0] - PITCH / 2
    strip_w = 12 * PITCH
    s.rect(strip_x, TOP_Y, strip_w, TOP_H, "termbox", rx=4)

    for i, p in enumerate(TOP):
        x = XS[i]
        cell_x = x - PITCH / 2
        color, cls = KIND[p["kind"]]
        if i:
            s.stroke(cell_x, TOP_Y, cell_x, TOP_Y + TOP_H, "#d0d5dd", 1.2)
        s.mid(x, TOP_Y + 20, "pin", p["t"])
        s.mid(x, TOP_Y + 38, "label", p["lab"])
        s.mid(x, TOP_Y + 54, "small", p["gpio"])
        s.mid(x, TOP_Y + 70, "small", p["dest"])
        cy = TOP_Y + TOP_H
        s.circle(x, cy, 4.5, color)

    # +3V3 rail (proposed inner)
    s.line(XS[0], Y33, XS[-1], Y33, "v33")
    s.circle(XS[0], Y33, 5, C_V33)
    s.text(XS[0] + 10, Y33 - 10, "v33text",
           "+3V3_TDISPLAY   module 3V · sensors · EC11 +   ·   do not back-feed")

    # ---- T-Display-S3 ----
    s.rect(DISP_X, DISP_Y, DISP_W, DISP_H, "part", rx=8)

    # USB-C on the left
    s.rect(DISP_X - 36, DISP_Y + 96, 36, 56, "part", rx=4)
    s.mid(DISP_X - 18, DISP_Y + 128, "small", "USB")

    # LCD
    lcd_x, lcd_y, lcd_w, lcd_h = DISP_X + 168, DISP_Y + 44, 720, 168
    s.rect(lcd_x, lcd_y, lcd_w, lcd_h, "lcd", rx=4)
    s.text(lcd_x + 20, lcd_y + 36, "lcdtitle", "T-Display-S3")
    s.text(lcd_x + 20, lcd_y + 58, "lcdsub", "LilyGo · ESP32-S3 · ST7789 320×170")
    s.text(lcd_x + 20, lcd_y + 80, "lcdsub",
           "setRotation(3) · origin is operator top-left")
    s.text(lcd_x + 20, lcd_y + 110, "lcdsub",
           "GPIO14  on-board button   ·   GPIO0  BOOT")
    s.text(lcd_x + 20, lcd_y + 128, "lcdsub",
           "LCD / backlight GPIOs reserved — do not reassign")
    s.text(lcd_x + 20, lcd_y + 154, "lcdsub",
           "RIGHT header on top · LEFT header on bottom · pin 12 nearest USB")

    # Buttons near USB
    s.rect(DISP_X + 18, DISP_Y + 88, 52, 28, "part", rx=3)
    s.mid(DISP_X + 44, DISP_Y + 106, "small", "BOOT")
    s.rect(DISP_X + 18, DISP_Y + 126, 52, 28, "part", rx=3)
    s.mid(DISP_X + 44, DISP_Y + 144, "small", "GPIO14")

    s.text(DISP_X + 18, DISP_Y + 196, "small", "LILYGO")

    # Top header pins (on the module edge)
    s.text(DISP_X + 8, DISP_Y - 18, "small", "RIGHT")
    for i, p in enumerate(TOP):
        x = XS[i]
        color, cls = KIND[p["kind"]]
        s.circle(x, Y_TOP_PIN, 5.5, color)
        s.mid(x, Y_TOP_PIN + 22, "pin", p["hdr"])
        s.mid(x - 12, DISP_Y - 8, "nctext" if p["kind"] == "nc" else "small",
              f"p{p['pin']}")

    # Bottom header pins
    s.text(DISP_X + 8, Y_BOT_PIN + 32, "small", "LEFT")
    for i, p in enumerate(BOT):
        x = XS[i]
        hdr_kind = p.get("hdr_kind", p["kind"])
        color, cls = KIND[hdr_kind]
        s.circle(x, Y_BOT_PIN, 5.5, color)
        s.mid(x, Y_BOT_PIN - 12, "pin", p["hdr"])
        s.mid(x - 12, Y_BOT_PIN + 22, "nctext" if hdr_kind == "nc" else "small",
              f"p{p['pin']}")

    # R6 / R7 geometry (PWM vertical hops the DIR tap at y_tap_dir)
    x_pwm = XS[4]
    x_dir = XS[5]
    x_t3 = XS[2]
    x_r6 = (XS[3] + XS[4]) / 2
    x_r7 = x_t3 + 20
    y_tap_dir = 368
    y_tap_pwm = 388

    # Wires: top strip → top pins. Only T1 joins +3V3; others hop that rail.
    for i, p in enumerate(TOP):
        x = XS[i]
        color, cls = KIND[p["kind"]]
        y0 = TOP_Y + TOP_H
        if not p.get("to_term", True):
            continue
        if p["kind"] == "v33":
            s.line(x, y0, x, Y33, "v33")
            s.circle(x, Y33, 4, C_V33)
            s.line(x, Y33, x, Y_TOP_PIN, "v33")
        elif p["kind"] == "nc":
            s.hop_v(x, y0, Y_TOP_PIN, [Y33], "nc", C_NC)
        elif p["t"] == "T5":
            # Hop +3V3 and the DIR pull-down run; R6 taps below that hop.
            s.hop_v(x, y0, Y_TOP_PIN, [Y33, y_tap_dir], cls, color)
        else:
            s.hop_v(x, y0, Y_TOP_PIN, [Y33], cls, color)
        if p["kind"] != "nc":
            s.circle(x, Y_TOP_PIN, 4, color)

    # R6 10 kΩ PWM pull-down (T5 → T3) and R7 10 kΩ DIR pull-down (T6 → T3)
    y_r = 404
    y_pd_gnd = DISP_Y - 22

    s.circle(x_pwm, y_tap_pwm, 4, C_IO)
    s.line(x_pwm, y_tap_pwm, x_r6, y_tap_pwm, "earth")
    s.line(x_r6, y_tap_pwm, x_r6, y_r, "earth")
    s.circle(x_r6, y_tap_pwm, 4, C_IO)
    s.res_v(x_r6, y_r, 28, 52, "10k")
    s.line(x_r6, y_r + 52, x_r6, y_pd_gnd, "gnd")
    s.line(x_r6, y_pd_gnd, x_t3, y_pd_gnd, "gnd")
    s.circle(x_t3, y_pd_gnd, 4, C_GND)
    s.text(x_r6 + 20, y_r + 24, "label", "R6")
    s.text(x_r6 + 20, y_r + 40, "small", "PWM pull-down")
    s.text(x_r6 + 20, y_r + 56, "small", "holds B LED off")

    s.circle(x_dir, y_tap_dir, 4, C_IO)
    s.line(x_dir, y_tap_dir, x_r7, y_tap_dir, "earth")
    s.line(x_r7, y_tap_dir, x_r7, y_r, "earth")
    s.circle(x_r7, y_tap_dir, 4, C_IO)
    s.res_v(x_r7, y_r, 28, 52, "10k")
    s.line(x_r7, y_r + 52, x_r7, y_pd_gnd, "gnd")
    s.line(x_r7, y_pd_gnd, x_t3, y_pd_gnd, "gnd")
    s.circle(x_t3, y_pd_gnd, 4, C_GND)
    s.text(x_r7 + 20, y_r + 24, "label", "R7")
    s.text(x_r7 + 20, y_r + 40, "small", "DIR pull-down")
    s.text(x_r7 + 20, y_r + 56, "small", "holds B LED off")

    # ---- EC11 (right of the module) ----
    ex, ey, ew, eh = 1368, 508, 268, 236
    s.rect(ex, ey, ew, eh, "part", rx=6)
    s.text(ex + 12, ey + 22, "label", "EC11  menu encoder")
    s.text(ex + 12, ey + 40, "small", "on-board · not on T17–T19")
    s.circle(ex + 48, ey + 88, 22, "#101828")
    a(f'<circle cx="{ex + 48}" cy="{ey + 88}" r="22" fill="none" '
      f'stroke="#667085" stroke-width="2"/>')
    s.text(ex + 80, ey + 72, "pin", "CLK   GPIO11")
    s.text(ex + 80, ey + 90, "pin", "DT    GPIO12")
    s.text(ex + 80, ey + 108, "pin", "SW    GPIO13")
    s.text(ex + 80, ey + 132, "pin", "+     +3V3")
    s.text(ex + 80, ey + 150, "pin", "GND   MCU_GND")
    s.text(ex + 12, ey + 180, "small", "3.3 V pull-ups on the breakout.")
    s.text(ex + 12, ey + 196, "small", "Never pull CLK / DT / SW to 5 V.")
    s.text(ex + 12, ey + 220, "enctext", "Short leads to LEFT header")

    # EC11 signal taps just under the LEFT header pins (GPIO13/12/11)
    enc_pins = [
        (4, 788, "SW"),
        (5, 808, "DT"),
        (6, 828, "CLK"),
    ]
    hop_xs = XS[7:]  # hop OPEN / LIM-L / ISENSE / HALL / 3V
    enc_end = ex + 8
    for idx, y, name in enc_pins:
        x = XS[idx]
        s.line(x, Y_BOT_PIN, x, y, "enc")
        s.circle(x, Y_BOT_PIN, 4, C_ENC)
        s.circle(x, y, 4, C_ENC)
        s.hop_h(y, x, enc_end, hop_xs, "enc", C_ENC)
        s.circle(enc_end, y, 4, C_ENC)
        s.text(enc_end + 8, y + 4, "enctext", name)

    # EC11 + from +3V3 (T24 / bottom 3V pin) and GND from rail
    x3 = XS[11]
    s.line(x3, Y_BOT_PIN, x3, 848, "v33")
    s.circle(x3, 848, 4, C_V33)
    s.line(x3, 848, enc_end, 848, "v33")
    s.circle(enc_end, 848, 4, C_V33)
    s.text(enc_end + 8, 852, "v33text", "+")

    s.line(enc_end, 868, enc_end, YGND, "gnd")
    s.circle(enc_end, 868, 4, C_GND)
    s.circle(enc_end, YGND, 5, C_GND)
    s.text(enc_end + 8, 872, "gndtext", "GND")

    # +3V3 riser to the right of the module (T24 / EC11 +, not through the LCD)
    xr33 = 1344
    s.line(XS[-1], Y33, xr33, Y33, "v33")
    s.line(xr33, Y33, xr33, Y_BOT_PIN, "v33")
    s.line(xr33, Y_BOT_PIN, XS[11], Y_BOT_PIN, "v33")
    s.circle(xr33, Y33, 4, C_V33)
    s.circle(xr33, Y_BOT_PIN, 4, C_V33)

    # GND rail — header GNDs are common on the module; proto rail is T14 / R6 / R7 / EC11
    s.line(XS[1], YGND, enc_end, YGND, "gnd")
    s.circle(XS[1], YGND, 5, C_GND)
    s.text(XS[1] + 10, YGND - 12, "gndtext",
           "MCU_GND   T2 T3 T11 T12 T14 T16–T18 · sensor / rocker / Board B LED return   ·   not −70V")

    # Bottom header → terminals. Signals hop MCU_GND; T14 joins it.
    for i, p in enumerate(BOT):
        x = XS[i]
        color, cls = KIND[p["kind"]]
        y1 = BOT_Y
        if not p.get("to_term", True):
            continue
        if p["kind"] == "nc":
            s.hop_v(x, Y_BOT_PIN, y1, [YGND], "nc", C_NC)
            continue
        if p["kind"] == "v5":
            s.line(x, Y_BOT_PIN, x, y1, "v5")
            s.circle(x, Y_BOT_PIN, 4, C_V5)
            continue
        if p["kind"] == "v33":
            s.hop_v(x, Y_BOT_PIN, y1, [YGND], "v33", C_V33)
            s.circle(x, Y_BOT_PIN, 4, C_V33)
            continue
        if p["kind"] == "gnd":
            s.line(x, Y_BOT_PIN, x, YGND, "gnd")
            s.circle(x, YGND, 4, C_GND)
            s.line(x, YGND, x, y1, "gnd")
            continue
        if p["t"] == "T22":
            # ACS712 10k / 20k divider on the ISENSE column
            yj = 960
            s.line(x, Y_BOT_PIN, x, yj, "earth")
            s.circle(x, Y_BOT_PIN, 4, C_IO)
            s.circle(x, yj, 4, C_IO)
            s.line(x, yj, x, yj + 8, "earth")
            s.res_v(x, yj + 8, 28, 48, "10k")
            s.hop_v(x, yj + 56, y1, [YGND], "earth", C_IO)
            s.line(x, yj, x - 40, yj, "earth")
            s.line(x - 40, yj, x - 40, yj + 8, "earth")
            s.res_v(x - 40, yj + 8, 28, 52, "20k")
            s.line(x - 40, yj + 60, x - 40, YGND, "gnd")
            s.circle(x - 40, YGND, 4, C_GND)
            s.text(x + 18, yj + 28, "label", "10k/20k")
            s.text(x + 18, yj + 44, "small", "ACS712 ≤ 3.3 V")
            continue
        s.hop_v(x, Y_BOT_PIN, y1, [YGND], cls, color)
        s.circle(x, Y_BOT_PIN, 4, color)

    # T13–T15 +5V bridge. LEFT p10 stays NC on the module; T15 is not that pin.
    y_br = BOT_Y - 22
    s.line(XS[0], BOT_Y, XS[0], y_br, "v5")
    s.hop_h(y_br, XS[0], XS[2], [XS[1]], "v5", C_V5)
    s.line(XS[2], y_br, XS[2], BOT_Y, "v5")
    s.circle(XS[0], y_br, 4, C_V5)
    s.circle(XS[2], y_br, 4, C_V5)
    s.text(XS[1] + 16, y_br - 16, "v5text", "T13–T15  +5V bridge")

    # T16–T18 sensor GND returns land on the MCU_GND rail (same net as T14).
    for i in (3, 4, 5):
        s.line(XS[i], YGND, XS[i], BOT_Y, "gnd")
        s.circle(XS[i], YGND, 4, C_GND)

    # ---- Bottom terminal strip T13–T24 ----
    s.rect(strip_x, BOT_Y, strip_w, BOT_H, "termbox", rx=4)

    for i, p in enumerate(BOT):
        x = XS[i]
        cell_x = x - PITCH / 2
        color, _ = KIND[p["kind"]]
        if i:
            s.stroke(cell_x, BOT_Y, cell_x, BOT_Y + BOT_H, "#d0d5dd", 1.2)
        if p["kind"] == "nc":
            s.rect(cell_x + 2, BOT_Y + 2, PITCH - 4, BOT_H - 4, "termnc", rx=3)
        s.mid(x, BOT_Y + 20, "pin", p["t"])
        s.mid(x, BOT_Y + 38, "label", p["lab"])
        s.mid(x, BOT_Y + 54, "small", p["gpio"])
        s.mid(x, BOT_Y + 70, "small", p["dest"])
        s.circle(x, BOT_Y, 4.5, color)
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

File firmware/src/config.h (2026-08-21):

#pragma once

#include <Arduino.h>

#include "ec11_calibration.h"

#if __has_include("wifi_secrets.h")
#include "wifi_secrets.h"
#endif

// Pin map — LilyGo T-Display-S3 (production). See docs/T-Display-S3_Pinout.md
// Motor rotation: AS5600 I²C. Genie optical encoder is not used.
// Firmware is not fully defined (NVS, snug, frozen env matrix still open).
namespace pins {

constexpr uint8_t kUserButton = 14;       // On-board button (cycle views)
constexpr uint8_t kPwm = 16;
constexpr uint8_t kCurrentSense = 2;      // ACS712-05B divider -> GPIO02
constexpr uint8_t kHallAnalog = 1;        // SS49E bottle door key -> GPIO01
constexpr uint8_t kLimitUpper = 17;
constexpr uint8_t kLimitLower = 3;
constexpr uint8_t kDirectionRelay = 21;
constexpr uint8_t kOpenButton = 10;       // Dual paralleled rockers, active-low
constexpr uint8_t kCloseButton = 18;      // Dual paralleled rockers, active-low
constexpr uint8_t kAs5600Sda = 43;
constexpr uint8_t kAs5600Scl = 44;
// EC11 rotary encoder — LEFT header GPIO11–13
constexpr uint8_t kRotaryClk = 11;
constexpr uint8_t kRotaryDt = 12;
constexpr uint8_t kRotarySw = 13;

}  // namespace pins

// --- AS5600 (motor shaft angle) ---
constexpr uint8_t kAs5600I2cAddr = 0x36;
constexpr uint8_t kAs5600RegRawAngle = 0x0C;  // 12-bit angle, MSB then LSB

// --- Bottle door key (SS49E, GPIO1) ---
constexpr uint16_t kHallAdcMin = 800;
constexpr uint16_t kHallAdcMax = 3200;
constexpr uint8_t kHallAdcSamples = 8;
constexpr float kHallDeviationFraction = 0.10f;

// --- Limits (near-end markers; docs/Limit_Marker_And_Snug.md) ---
// NC-to-GND, INPUT_PULLUP. HIGH = marker or open wire. LOW is travel.
constexpr bool kLimitActiveLow = false;
constexpr uint8_t kLimitDebounceCount = 3;

// --- Trigger / relay ---
constexpr bool kTriggerActiveLow = true;
constexpr bool kDirectionRelayOpenHigh = true;
constexpr bool kRotarySwitchActiveLow = true;
constexpr uint32_t kRelaySettleMs = 25;
constexpr uint32_t kPwmBlankBeforeDirMs = 100;

// --- PWM ---
// ESP32-S3 Arduino 2.x LEDC uses the 40 MHz XTAL clock. At 12-bit that
// caps frequency at ~9.8 kHz, so ledcSetup(15000, 12) fails and the pin
// stays LOW. 10-bit allows 15 kHz (max ~39 kHz).
constexpr uint32_t kPwmFrequencyHz = 15000;
constexpr uint8_t kPwmResolutionBits = 10;
constexpr uint16_t kPwmMaxDuty = (1u << kPwmResolutionBits) - 1u;
constexpr bool kPwmInvertDuty = false;

// --- Move profile (~12 s total) ---
constexpr uint32_t kMoveRampUpMs = 3000;
constexpr uint32_t kMoveCruiseMs = 6000;
constexpr uint32_t kMoveRampDownMs = 3000;
constexpr uint16_t kMoveCruiseDuty = 512;  // ~50% of 10-bit max (1023)

// --- Current sensor (Hall module OUT -> divider -> ADC GPIO2) ---
// ACS712-05B: 185 mV/A, 10k/20k divider. Bench and production use this module.
constexpr float kAcs712ModuleZeroVolts = 2.50f;
constexpr float kAcs712MvPerAmp = 185.0f;
constexpr float kAcs712DividerRatio = 20.0f / 30.0f;
constexpr uint8_t kAcs712AdcSamples = 16;
constexpr uint32_t kAcs712CalDelayMs = 200;
// Preferred ACS712 path is fused +70 V high rail (true motor current) → false.
// Set true only for a return-path / chopped-current build.
constexpr bool kOvercurrentScaleByDuty = false;
constexpr float kOvercurrentMinDutyFraction = 0.15f;
constexpr float kOvercurrentTripAmps = 2.5f;
constexpr uint32_t kOvercurrentHoldMs = 150;

// --- Safety ---
constexpr uint32_t kMotionWatchdogMs = 500;
constexpr uint16_t kMotionMinDuty = 64;  // ~6% of 10-bit max
constexpr int32_t kMinPositionProgressCounts = 5;

// --- Loop ---
constexpr uint32_t kControlLoopMs = 10;
constexpr uint32_t kStatusIntervalMs = 1000;
constexpr uint32_t kWatchdogTimeoutSec = 3;
constexpr uint32_t kSerialBaud = 115200;

// --- WiFi web dashboard (STA when joined; SoftAP if STA is down) ---
constexpr bool kEnableWebPortal = true;
#ifndef PR_HAS_AP_DEFAULTS
constexpr char kApSsid[] = "PrivateReserve";
constexpr char kApPassword[] = "reserved";  // WPA2; min 8 chars; "" = open network
#endif
constexpr uint16_t kWebPort = 80;
constexpr uint32_t kWebSampleMs = 200;

// --- OTA (T-Display STA + ArduinoOTA; secrets in wifi_secrets.h) ---
#if defined(TDISPLAY_S3_DEBUG) || defined(TDISPLAY_S3_OTA) || \
    defined(TDISPLAY_S3_EC11) || defined(TDISPLAY_S3_GPIO) || \
    defined(TDISPLAY_S3_PWM) || defined(TDISPLAY_S3_MAGSCAN) || \
    defined(TDISPLAY_S3_PROD)
constexpr bool kEnableOta = true;
#else
constexpr bool kEnableOta = false;
#endif
constexpr char kOtaHostname[] = "private-reserve";

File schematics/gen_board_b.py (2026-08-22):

#!/usr/bin/env python3
"""Generate Board_B.svg — floating gate-driver service schematic."""

from pathlib import Path

OUT = Path(__file__).with_name("Board_B.svg")

W, H = 2280, 1420

# Rails — below the domain titles, with a gap between +12V and +5V
Y12, Y5, Y70 = 292, 356, 1296
RX0, RX1 = 390, 1510

# Earth GND (same Y as −70V, never joined)
YGND = 1296
GX0, GX1 = 70, 340

ISO_X = 356

# Signal rows
YPWM = 640
YDIR = 1000
Y_MID70 = 860

# Colors
C_EARTH = "#175cd3"
C_GND = "#101828"
C_12 = "#ca8504"
C_5 = "#c11574"
C_70 = "#78716c"
C_ISO = "#7f56d9"
C_INK = "#222"


def esc(s):
    return s.replace("&", "&amp;").replace("<", "&lt;").replace(">", "&gt;")


class Svg:
    def __init__(self):
        self.b = []

    def add(self, s):
        self.b.append(s)

    def raw(self, s):
        self.add(s)

    def line(self, x1, y1, x2, y2, cls):
        self.add(
            f'<line x1="{x1}" y1="{y1}" x2="{x2}" y2="{y2}" class="{cls}"/>'
        )

    def path(self, d, cls):
        self.add(f'<path d="{d}" class="{cls}"/>')

    def circle(self, x, y, r, fill):
        self.add(f'<circle cx="{x}" cy="{y}" r="{r}" fill="{fill}"/>')

    def text(self, x, y, cls, t):
        self.add(f'<text x="{x}" y="{y}" class="{cls}">{esc(t)}</text>')

    def rect(self, x, y, w, h, cls, rx=5):
        self.add(
            f'<rect x="{x}" y="{y}" width="{w}" height="{h}" '
            f'rx="{rx}" class="{cls}"/>'
        )

    def poly(self, pts, stroke, fill="none", sw=3):
        p = " ".join(f"{x},{y}" for x, y in pts)
        self.add(
            f'<polygon points="{p}" fill="{fill}" stroke="{stroke}" '
            f'stroke-width="{sw}"/>'
        )

    def stroke(self, x1, y1, x2, y2, color, sw=3):
        self.add(
            f'<line x1="{x1}" y1="{y1}" x2="{x2}" y2="{y2}" '
            f'stroke="{color}" stroke-width="{sw}" '
            f'stroke-linecap="round"/>'
        )

    def res_h(self, x, y, w, h, value):
        self.rect(x, y - h / 2, w, h, "part", rx=2)
        self.text(x + 6, y + 4, "pin", value)

    def res_v(self, x, y, w, h, value):
        self.rect(x - w / 2, y, w, h, "part", rx=2)
        self.text(x - w / 2 + 3, y + h / 2 + 4, "pin", value)

    def cap_v(self, x, yt, yb, value):
        """Vertical capacitor. Plates between yt (top lead) and yb (bottom)."""
        mid = (yt + yb) / 2
        g = 5
        self.stroke(x, yt, x, mid - g, C_INK, 3)
        self.stroke(x - 12, mid - g, x + 12, mid - g, C_INK, 3)
        self.stroke(x - 12, mid + g, x + 12, mid + g, C_INK, 3)
        self.stroke(x, mid + g, x, yb, C_INK, 3)
        self.text(x + 14, mid + 4, "pin", value)

    def led_right(self, x, y, color):
        """Anode at left (x), cathode bar at x+36, center y."""
        self.poly(
            [(x, y - 16), (x, y + 16), (x + 28, y)],
            color,
        )
        self.stroke(x + 32, y - 16, x + 32, y + 16, color, 3)
        # light arrows
        self.stroke(x + 10, y - 28, x + 22, y - 40, color, 2)
        self.stroke(x + 22, y - 22, x + 34, y - 34, color, 2)

    def diode_v(self, x, yk, ya, color, cathode_up=True):
        """Vertical diode. Fixed symbol size; leads fill yk↔ya."""
        body = 28
        mid = (yk + ya) / 2
        if cathode_up:
            bar_y = mid - body / 2
            base_y = mid + body / 2
            tip_y = bar_y
            self.stroke(x, yk, x, bar_y, color, 3)
            self.stroke(x - 14, bar_y, x + 14, bar_y, color, 3)
            self.poly([(x - 12, base_y), (x + 12, base_y), (x, tip_y)], color)
            self.stroke(x, base_y, x, ya, color, 3)
        else:
            bar_y = mid + body / 2
            base_y = mid - body / 2
            tip_y = bar_y
            self.stroke(x, ya, x, base_y, color, 3)
            self.poly([(x - 12, base_y), (x + 12, base_y), (x, tip_y)], color)
            self.stroke(x - 14, bar_y, x + 14, bar_y, color, 3)
            self.stroke(x, bar_y, x, yk, color, 3)

    def npn(self, x, y):
        """NPN. (x,y) = device center. C up, E down, B left."""
        self.stroke(x + 10, y - 36, x + 10, y + 36, C_INK, 3)
        self.stroke(x + 10, y - 22, x + 28, y - 22, C_INK, 3)
        self.stroke(x + 10, y + 22, x + 28, y + 22, C_INK, 3)
        self.stroke(x + 28, y - 22, x + 28, y - 48, C_INK, 3)  # C
        self.stroke(x + 28, y + 22, x + 28, y + 48, C_INK, 3)  # E
        self.stroke(x - 28, y, x + 10, y, C_INK, 3)  # B
        # emitter arrow
        self.poly(
            [(x + 28, y + 48), (x + 22, y + 34), (x + 34, y + 34)],
            C_INK,
            fill=C_INK,
            sw=1,
        )
        return {
            "b": (x - 28, y),
            "c": (x + 28, y - 48),
            "e": (x + 28, y + 48),
        }

    def nmos(self, x, y):
        """IEEE-style N-MOSFET. Isolated gate, broken channel, S arrow in."""
        gx, ch = x + 6, x + 26
        self.stroke(x - 20, y, gx, y, C_INK, 3)  # G lead
        self.stroke(gx, y - 36, gx, y + 36, C_INK, 3)  # gate plate
        for yy in (y - 24, y, y + 24):
            self.stroke(gx + 8, yy, ch, yy, C_INK, 3)
        self.stroke(ch, y - 28, ch, y - 20, C_INK, 3)
        self.stroke(ch, y - 4, ch, y + 4, C_INK, 3)
        self.stroke(ch, y + 20, ch, y + 28, C_INK, 3)
        self.stroke(ch, y - 24, ch, y - 52, C_INK, 3)  # D
        self.stroke(ch, y + 24, ch, y + 52, C_INK, 3)  # S
        self.poly(
            [(ch, y + 24), (ch - 6, y + 38), (ch + 6, y + 38)],
            C_INK,
            fill=C_INK,
            sw=1,
        )
        return {
            "g": (x - 20, y),
            "d": (ch, y - 52),
            "s": (ch, y + 52),
        }

    def inverter(self, x, y, w=42):
        """Inverting buffer. Input (x,y), output x+w."""
        self.poly(
            [(x, y - 16), (x, y + 16), (x + w - 10, y)],
            C_INK,
        )
        self.circle(x + w - 5, y, 5, "#fff")
        self.add(
            f'<circle cx="{x + w - 5}" cy="{y}" r="5" fill="none" '
            f'stroke="{C_INK}" stroke-width="2.4"/>'
        )
        return x + w
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

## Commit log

2026-08-22 Add Board A–C service schematics and rename DIR_OR to DIR.
2026-08-22 Add printable 3mf bodies for the puck, encoder cover, standoff, and ACS712 mount.
    [Current Load Sensor Mount - v3.3mf, Dual PermaProto Standoff-Body.3mf, Rotary Encoder Cover10-Body.3mf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]
2026-08-22 Give ACS712 its own +5V and extra GND terminals on Board A.
    T15 is a T13–T15 +5V bridge, not LEFT p10. T16–T18 drop onto the MCU_GND rail so sensor returns do not steal EC11 header pins.
2026-08-22 Add opening and current-table LCD shots to the README.
2026-08-22 Make diagnostic jog a timed EC11 queue that does not depend on the shaft encoder.
    Duty and step are edited on the jog page, leftover time expires on its own, and current is display-only.
2026-08-28 Show AS5600 I2C ACK separately from magnet STATUS on Diagnostics.
    The menu reports no i2c versus no mag so a live bus is visible when the magnet is unreadable, and operator docs and Board A pull-downs stay in sync.
2026-08-28 Split diagnostic jog into time and count pages, and keep time jog off the AS5600 bus.
    Time per detent no longer stalls on I2C NACKs; position jog runs only while the magnet and bus are healthy. Operator docs and PDFs match the two screens.
    [app.cpp, app_view.cpp, as5600.cpp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]
2026-08-28 Fix EC11 HOLD after the settings-blob shift, and name why position jog is locked.
    Append jog_step_counts so NVS hold-min is not overwritten, fire HOLD at min, and show I2C vs magnet STATUS on the locked banner.
    [app.cpp, app_view.cpp, types.h]
2026-08-28 Make position jog relative and poll the encoder when that screen opens.
    Prime the stall watchdog so count jog is not aborted on the first PWM frame, skip travel-cap while jogging, and cancel a leftover time jog so STATUS is not stale.
    [app.cpp, door.cpp, door.h]
